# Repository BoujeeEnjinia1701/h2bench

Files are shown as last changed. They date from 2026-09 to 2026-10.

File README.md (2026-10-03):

# H2Bench

     

**Area:** Hydrogen · **TRL:** 3 of 9 (proof of concept on paper) · **Value-engineering target:** USD 885 (estimated cost USD 1056) · **Difficulty:** 4 of 5

A teaching bench that splits water with a small electrolyzer, stores a few liters of hydrogen at low pressure and runs a fuel cell, with meters so students can measure efficiency at each step. Protected by H2Guard.

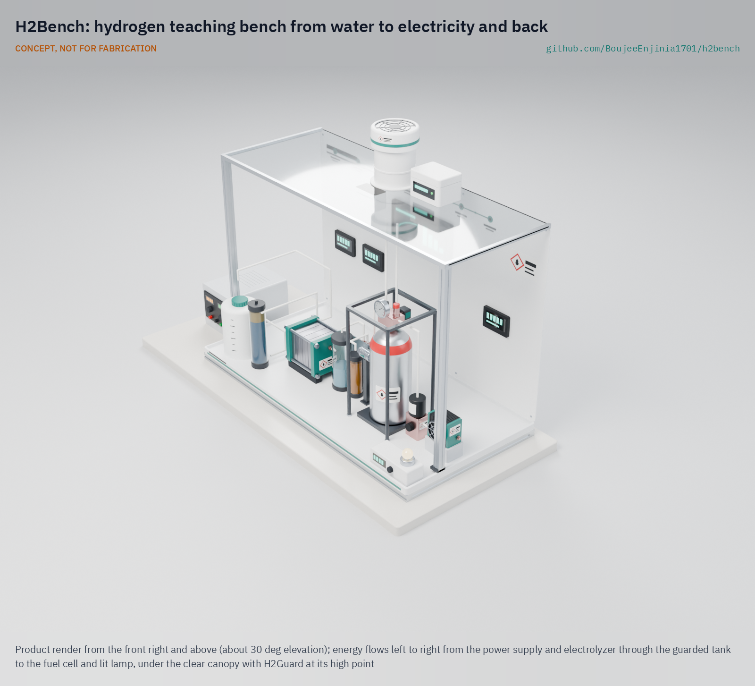
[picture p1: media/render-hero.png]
H2Bench: hydrogen teaching bench from water to electricity and back, product render


[Exploded render](media/render-exploded.png) · [Front render](media/render-front.png) · [Interactive 3D model](media/viewer.html) · [Concept blueprint (PDF)](media/concept-blueprint.pdf) · [General arrangement HBN-DWG-001 (PDF)](cad/drawings/HBN-DWG-001.pdf) · [Sizing calculations](docs/04-calcs/01-sizing.md) · [Prototype build plan](docs/05-build-plan.md) · [Design decisions](docs/06-design-decisions.md) · [Review note](docs/REVIEW.md)

## Concept rationale

Measuring electricity in, hydrogen made and electricity out gives students an honest sense of where hydrogen fits and where it does not. H2Bench works at tens of watts, large enough that meter and wiring errors do not swamp the result and small enough that the whole hydrogen inventory (about 7.9 L at up to 300 kPa gauge) could be released into a classroom without approaching a flammable mixture. A rigid buffer tank lets students count the hydrogen with the gas law, and the same pressure feeds the fuel cell without a compressor.

It is open and garage-buildable because the barrier for schools is cost and trust. A branded 12 W fuel cell stack alone lists at $482 to $576 ([Fuel Cell Shop](https://www.fuelcellshop.com/7-types-of-small-fuel-cell-by-price-point/t1363?currency=usd), [Fuel Cell Store](https://www.fuelcellstore.com/horizon-12-watt-pem-fuel-cell)), well over half the whole $850 bench budget, and a sealed kit cannot be inspected by a safety officer. Every part of H2Bench is off the shelf, the design files are under CERN-OHL-S-2.0, and its safety chain is the portfolio's own open H2Guard detector and interlock.

## Burning platform

Hydrogen is moving from strategy to construction faster than the people who can judge it are trained. Global hydrogen demand was almost 100 Mt in 2024, but low-emissions hydrogen was still less than 1 % of production, and installed water electrolysis capacity was only about 2 GW ([IEA, Global Hydrogen Review 2025](https://www.iea.org/reports/global-hydrogen-review-2025/executive-summary)). The European Union alone aims to produce 10 Mt of renewable hydrogen a year by 2030 ([European Commission](https://energy.ec.europa.eu/topics/eus-energy-system/hydrogen_en)).

The workforce to build this is short: more than half of some 700 energy companies, unions and training institutions surveyed by the IEA report critical hiring bottlenecks ([IEA, 2025](https://www.iea.org/news/energy-employment-has-surged-but-growing-skills-shortages-threaten-future-momentum)). And the key number every student should leave with is sobering: converting electricity to hydrogen and back with fuel cells returns only 27.4 to 48 % of the energy ([Oxford Institute for Energy Studies, 2025](https://www.oxfordenergy.org/wpcms/wp-content/uploads/2025/07/ET48-Power-to-Hydrogen-to-Power.pdf)). H2Bench lets them measure it.

## Where it could be used

### By industry

| Industry | Use |
| --- | --- |
| Secondary and vocational schools | A practical that follows one packet of energy from electricity to hydrogen and back, with students calculating each efficiency |
| Hydrogen technician training | Safe-handling drills on real hardware: purge, leak check, interlock test and shutdown |
| Universities | Electrochemistry and energy labs: polarization curves, Faraday efficiency, gas law and uncertainty analysis |
| Energy utilities and project developers | Induction training for staff moving from gas, power or oil into hydrogen projects |
| Science centers and outreach | Supervised demonstrations of hydrogen production and use, with a visible lamp load |
| Public sector and policy training | Showing decision makers the measured round-trip loss behind hydrogen storage proposals |

### By country or region

| Country or region | Why it matters there |
| --- | --- |
| European Union | Targets 10 Mt of domestic renewable hydrogen and 10 Mt of imports a year by 2030 ([European Commission](https://energy.ec.europa.eu/topics/eus-energy-system/hydrogen_en)), which needs technicians across member states. |
| United States | The DOE Hydrogen Program names teachers and students as target audiences and notes "a general lack of awareness of hydrogen as an energy alternative" ([US DOE](https://www.hydrogen.energy.gov/program-areas/education)). |
| India | The National Green Hydrogen Mission targets 5 Mt a year by 2030 and projects over 600,000 jobs; about 5,600 people had been certified in hydrogen skills ([PIB, Government of India](https://www.pib.gov.in/PressNoteDetails.aspx?id=155990&NoteId=155990&ModuleId=3)). |
| China | Holds 65 % of global installed electrolysis capacity ([IEA, 2025](https://www.iea.org/reports/global-hydrogen-review-2025/executive-summary)), the largest base of electrolyzers that trained operators will run. |
| Chile | Its national strategy aims to produce the world's most cost-competitive green hydrogen by 2030 and to rank among the three leading exporters by 2040 ([IEA policy database](https://www.iea.org/policies/12973-national-strategy-for-green-hydrogen)). |
| Namibia | The vice-chancellor of the Namibia University of Science and Technology has warned of a talent gap of up to 130,000 green hydrogen workers by 2040 ([The Namibian, 2025](https://www.namibian.com.na/namibia-risks-130-000-worker-shortage-in-green-hydrogen-sector/)); the university's IGNITE GH2 project is retraining 685 unemployed graduates and 40 instructors ([NUST, 2026](https://www.nust.na/igniting-namibias-green-hydrogen-dream-science-building-national-tvet-workforce-green-hydrogen)). |

## What sparked the idea

The idea traces back to William Grove's gaseous voltaic battery, first described in 1842 ([Grove, *Philosophical Magazine* 21, 1842](https://doi.org/10.1080/14786444208621600)). Grove recombined hydrogen and oxygen on platinum electrodes in dilute sulfuric acid to make a current, and he used that current to decompose water, running the cycle in both directions on one bench. His 1843 paper to the Royal Society set out to establish "the rationale of its action" by experiment and reports the battery decomposing water, among other compounds ([Grove, *Philosophical Transactions* 133, 1843](https://doi.org/10.1098/rstl.1843.0009)). H2Bench takes the same loop, electricity to hydrogen and back, and adds what a classroom needs that Grove's apparatus lacked: a meter at every stage, a counted quantity of gas and a hardwired safety chain.

## Problem

Students hear about the hydrogen economy but rarely measure it. Teaching kits are either toys or costly lab systems, and neither shows round-trip losses clearly. Branded 12 W fuel cell stacks alone list at about $480 to $580, and schools need detection and ventilation before they will host any hydrogen rig.

## Concept

A teaching bench that splits water with a small electrolyzer, stores a few liters of hydrogen at low pressure and runs a fuel cell, with meters so students can measure efficiency at each step. Protected by H2Guard.

In one lesson a 70 W PEM electrolyzer fills a 2 L tank from 70 to 300 kPa gauge in 17.7 min; a 12 W class fuel cell then runs a lamp at 10.8 W for 29.0 min. Students log every stage at 1 Hz and find a round trip of about 25 % (HHV basis), each stage measurable to within ±2 %. These are paper figures from the TRL 3 sizing note HBN-CAL-001, not measurements.

At TRL 3 the design meets eleven of its sixteen requirements on paper. Value-engineering target: USD 885. Estimated cost of the constructable design: USD 1056 (USD 171 over the target). The H2Guard interlock, electrolyzer back-pressure and hydrogen purity at the fuel cell are at risk. The model now carries the decisions of 2026-10-02: a catalytic deoxidizer between the separator and the drier, a 10 mm deck, and the bench supply beside the bench, which brings the bench to 24.4 kg (R13 met) ([design decisions register](docs/06-design-decisions.md)); see [docs/REVIEW.md](docs/REVIEW.md).

Full design precis: [docs/02-concept.md](docs/02-concept.md)

## Key components

- PEM electrolyzer stack, about 70 W (under 100 W)
- 2 L buffer tank at up to 300 kPa gauge, with a 310 kPa gauge supply cut, a 325 kPa gauge relief valve, pressure and temperature sensing (metal hydride and gasbag kept as options)
- PEM fuel cell, 12 W class (under 50 W), with regulator and solenoid valve
- Power meters on each stage, with a logger and display
- Water deionizer cartridge and reservoir
- H2Guard detector and interlock, sensing at the high point of a canopy hood
- Bench frame and canopy hood

The priced bill of materials is in [bom/bom.csv](bom/bom.csv). Value-engineering target: USD 885, with the bench supply in the kit. Estimated cost of the constructable design: USD 1056 (USD 171 over the target); USD 991 without the bench power supply; H2Guard excluded. See [docs/REVIEW.md](docs/REVIEW.md).

## Building the prototype

The design is constructable: every part can be cut, folded, drilled or bought, and fastens to the parts next to it ([HBN-DDR-003](docs/decisions/0003-design-for-construction.md)). The bench is a slotted aluminium extrusion frame under a 12 mm HDPE deck, with four posts and a top frame carrying the polycarbonate canopy and the printed instrument panel; every component stands on a small folded or cut mount screwed to the deck. The [prototype build plan](docs/05-build-plan.md) shows each component's making sketch, every joint and all 14 assembly steps in pictures, with the leak, cut-switch and interlock checks that come before any hydrogen is made. Decisions still open are in the [design decisions register](docs/06-design-decisions.md).

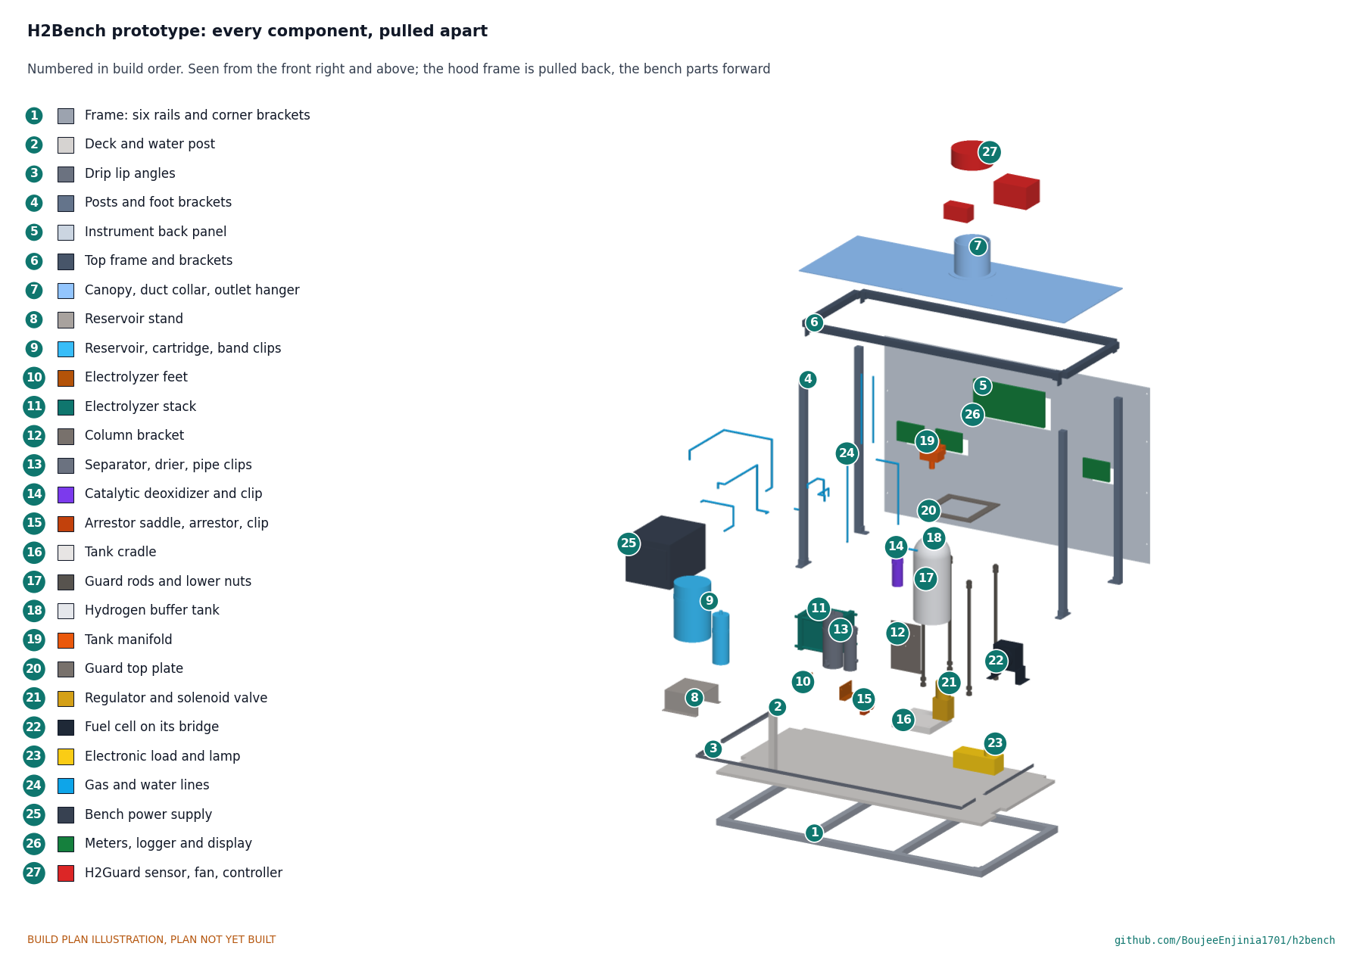
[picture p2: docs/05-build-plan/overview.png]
H2Bench prototype: every component, pulled apart and numbered in build order


## Safety

> Hydrogen is flammable from about 4 to 74 % in air and ignites very easily. Keep storage small and at low pressure (about 7.9 L at up to 300 kPa gauge), use only pressure parts rated 1 MPa or more, keep air out of the tank, and operate only with H2Guard active and under supervision. The power supply is mains powered; use an RCD or GFCI. Research and teaching use only; not certified laboratory equipment.

## Repository layout

| Folder | Contents |
| --- | --- |
| `docs/` | Problem, concept, requirements, calculations and design decisions |
| `cad/src/` | build123d Python source, the source of truth for all geometry |
| `cad/step/`, `cad/stl/` | Exported models for FreeCAD, other CAD tools and printing |
| `cad/drawings/` | 2D sketches and dimensioned drawings |
| `bom/` | Bill of materials |
| `electronics/` | KiCad schematics and PCB layouts |
| `firmware/` | Microcontroller code |
| `media/` | Renders, perspectives and photos |
| `build-log/` | Dated prototyping notes |

## Documentation

Controlled documents follow the portfolio [documentation standard](.kit/STANDARDS.md). Each carries a document ID (HBN-PRC-001 for the precis), a version and a revision history. Branded PDFs are built with `python .kit/render.py` and attached to GitHub Releases when a document is tagged, for example `HBN-PRC-001/v1.0`.

## Credits

Designed by Amish Chadha. See [CONTRIBUTORS.md](CONTRIBUTORS.md) for roles. To cite this design, use [CITATION.cff](CITATION.cff) (GitHub shows it as "Cite this repository").

AI assistance (Claude) was used to accelerate concept renders, prototype documentation and first-pass sizing calculations. Design direction and all decisions are Amish Chadha's, recorded in this repository's decision records (`docs/decisions/`).

## Licenses

- **Hardware** (CAD, drawings, BOM, electronics): [CERN-OHL-S v2](LICENSE)
- **Software** (firmware, scripts, notebooks): [MIT](LICENSE-SOFTWARE)

A project of the [Design Molecule](https://designmolecule.com) lab.

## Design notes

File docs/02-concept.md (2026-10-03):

---
doc_id: HBN-PRC-001
title: H2Bench design precis
project: H2Bench
doc_type: Design precis
version: "0.8"
status: Draft
date: '2026-10-02'
author: Amish Chadha
license: CERN-OHL-S-2.0
revisions:
- version: "0.1"
  date: '2026-09-25'
  author: Amish Chadha
  change: Initial scaffold
- version: "0.2"
  date: '2026-09-25'
  author: Amish Chadha
  change: Populate to TRL 2 (architecture, first-order numbers, design choices, safety, media)
- version: "0.3"
  date: '2026-09-25'
  author: Amish Chadha
  change: TRL 3 update; choices adopted for TRL 3 (HBN-DDR-001), numbers checked in HBN-CAL-001, parametric model and HBN-DWG-001, vent needle valve, media refreshed
- version: "0.4"
  date: '2026-09-25'
  author: Amish Chadha
  change: Recommendations accepted by Amish (DDR-002)
- version: "0.5"
  date: '2026-09-26'
  author: Amish Chadha
  change: Budget approved by Amish ($885)
- version: "0.6"
  date: '2026-10-01'
  author: Amish Chadha
  change: Constructable design (HBN-DDR-003) with posts and top frame, mounts, water lines; mass, cost against the value-engineering target, GA Rev P3; build plan and decisions register linked
- version: "0.7"
  date: '2026-10-02'
  author: Amish Chadha
  change: "Decisions of 2026-10-02: deoxidizer, tank material, worksheets and first use, H2Guard interface proposal; separator drain and demonstration-first safety rules"
- version: "0.8"
  date: '2026-10-02'
  author: Amish Chadha
  change: "Decisions carried into the design (2026-10-02): deoxidizer (line 19), 10 mm deck, supply beside the bench; figures from HBN-CAL-001 v0.6"
---

# H2Bench design precis

## Summary

H2Bench is a teaching bench that turns about 21 Wh of electricity into about 4.5 L of usable hydrogen in an 18 min fill, holds it in a 2 L tank at up to 300 kPa gauge (supply cut at 310 kPa gauge, relief at 325 kPa gauge), and returns about 5 Wh through a 12 W class fuel cell over about 29 min. Every stage is metered, so students measure a round-trip efficiency of about 25 % (estimate, HHV basis) from their own data and see where the other 75 % goes. The bench sits on an existing lab table under a canopy hood and runs only while the portfolio's H2Guard detector, extraction fan and interlock are active. All figures are checked in the calculation note HBN-CAL-001; they are paper estimates, not measurements.

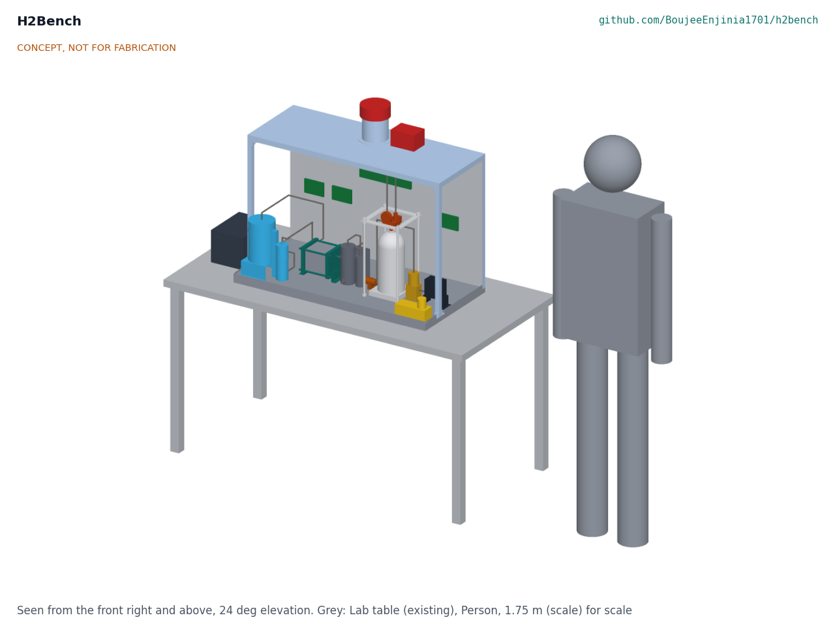
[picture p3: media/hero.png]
Hero render


*Figure 1. H2Bench on an existing lab table with a 1.75 m person for scale. Energy flows left to right: power supply, water, electrolyzer, gas treatment, buffer tank, regulator, fuel cell and lamp. Constructable model from `cad/src/model.py` (HBN-DDR-003).*

## How it works

A lesson runs in two halves.

1. **Fill (about 18 min).** The bench power supply (4) drives the PEM electrolyzer stack (6) in constant-current mode at about 9 A and 7.8 V. Deionized water from the reservoir (5) is split: oxygen vents into the hood, and hydrogen passes through the separator (7), the catalytic deoxidizer (19) and the drier (7), the check valve and flame arrestor (8), and into the buffer tank (9). The electrolyzer pushes the tank from 70 to 300 kPa gauge on its own; there is no compressor. If the fill is not stopped at 300 kPa gauge, a pressure switch on the manifold opens at 310 kPa gauge and a relay breaks the supply line, so the relief valve (325 kPa gauge) is only a backup. The cut is hardwired and does not depend on the logger firmware. Students log current, voltage, tank pressure and temperature, and compute the hydrogen made from the gas law and from Faraday's law. The difference is the Faraday efficiency.
2. **Discharge (about 29 min).** The solenoid valve and regulator (11) feed the fuel cell (12) at about 50 kPa gauge. The fuel cell runs the electronic load and lamp (13) at about 1.5 A. Students log power out and tank pressure fall, and plot the fuel cell's polarization curve by stepping the load.

The meters and logger (14) record every quantity at 1 Hz to a CSV file. The H2Guard sensor at the high point of the canopy hood (15) watches for hydrogen; on alarm it cuts the power supply output, closes the tank solenoid and runs the extraction fan at full speed.

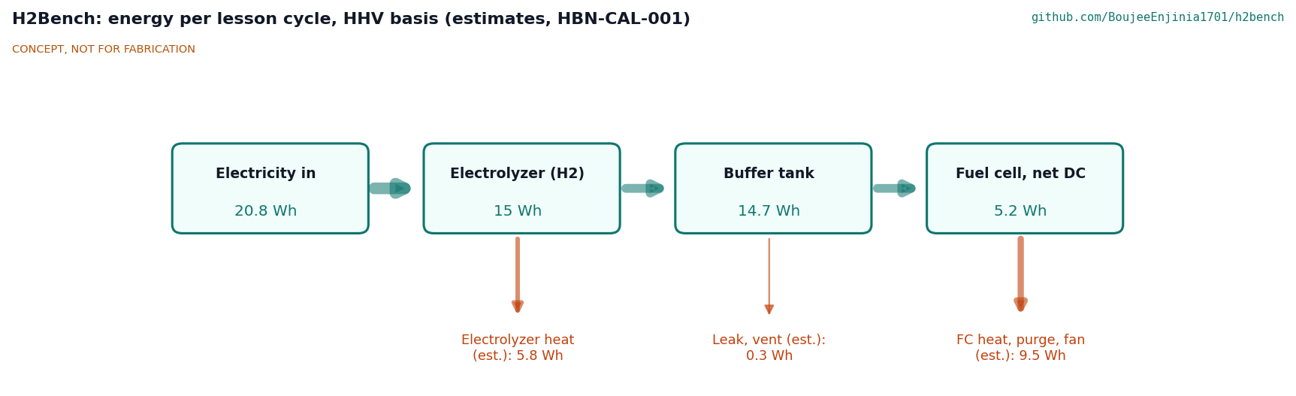
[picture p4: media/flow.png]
Energy flow


*Figure 2. Energy per lesson cycle, HHV basis, from HBN-CAL-001. All values are paper estimates: electrolyzer 72.2 % (voltage efficiency 75.9 %, Faraday efficiency 95 %), 2 % lost to leaks and venting in storage, fuel cell 35.5 % net (0.60 V per cell, 95 % fuel utilization, 0.9 W fan and controls).*

## Main components

Table 1. Main components. Numbers match `bom/bom.csv` and Figure 3.

| No. | Component | Function | Key figure (estimate) |
| --- | --- | --- | --- |
| 1 | Bench deck and extrusion frame | Carries everything, sits on the lab table | 900 x 450 mm |
| 2 | Instrument back panel | Printed energy-chain schematic; carries the meters | 570 mm tall |
| 3 | Canopy hood, duct and posts | Collects rising hydrogen at one point for sensing and extraction | 100 mm duct |
| 4 | Bench DC power supply | Constant-current drive for the electrolyzer | 0 to 30 V, 0 to 10 A |
| 5 | DI water reservoir and deionizer | Feed water at 1 µS/cm or less | About 3.4 g water used per fill |
| 6 | PEM electrolyzer stack | Splits water; pressurizes the tank | 4 cells, about 70 W, about 250 mL/min H2 |
| 7 | Gas and water separator, drier | Returns water; dries the hydrogen | Silica gel with indicator |
| 8 | Check valve and flame arrestor | Stops backflow and flame propagation into the stack | 7 kPa cracking pressure |
| 9 | Hydrogen buffer tank with guard | Stores the lesson's hydrogen | 2 L, 300 kPa gauge working, rated 1 MPa or more |
| 10 | Tank manifold | Pressure and temperature for the gas law; relief; gauge; vent needle valve; high-pressure cut switch | Cut at 310 kPa gauge; relief at 325 kPa gauge; vent in 3 min or more |
| 11 | Regulator and solenoid valve | Feeds the fuel cell; closes on alarm or power loss | About 50 kPa gauge out |
| 12 | PEM fuel cell | Converts hydrogen back to electricity | 12 W class, 13 cells, 154 mL/min H2 supplied |
| 13 | Electronic load and lamp | Steps the load for polarization curves; shows the output | 0 to 3 A |
| 14 | Meters, logger and display | Three power monitors, pressure and temperature, CSV at 1 Hz; relay that breaks the electrolyzer supply when the line 10 switch opens | ±1 % power; relay 10 A DC or more |
| 15 | H2Guard sensor, controller and fan | Detection, extraction and interlock (H2Guard project) | See H2Guard |
| 19 | Catalytic deoxidizer | Reacts oxygen carried across the stack membrane back into water before the drier | Palladium cartridge, 32 x 120 mm; assumed 99 % conversion |

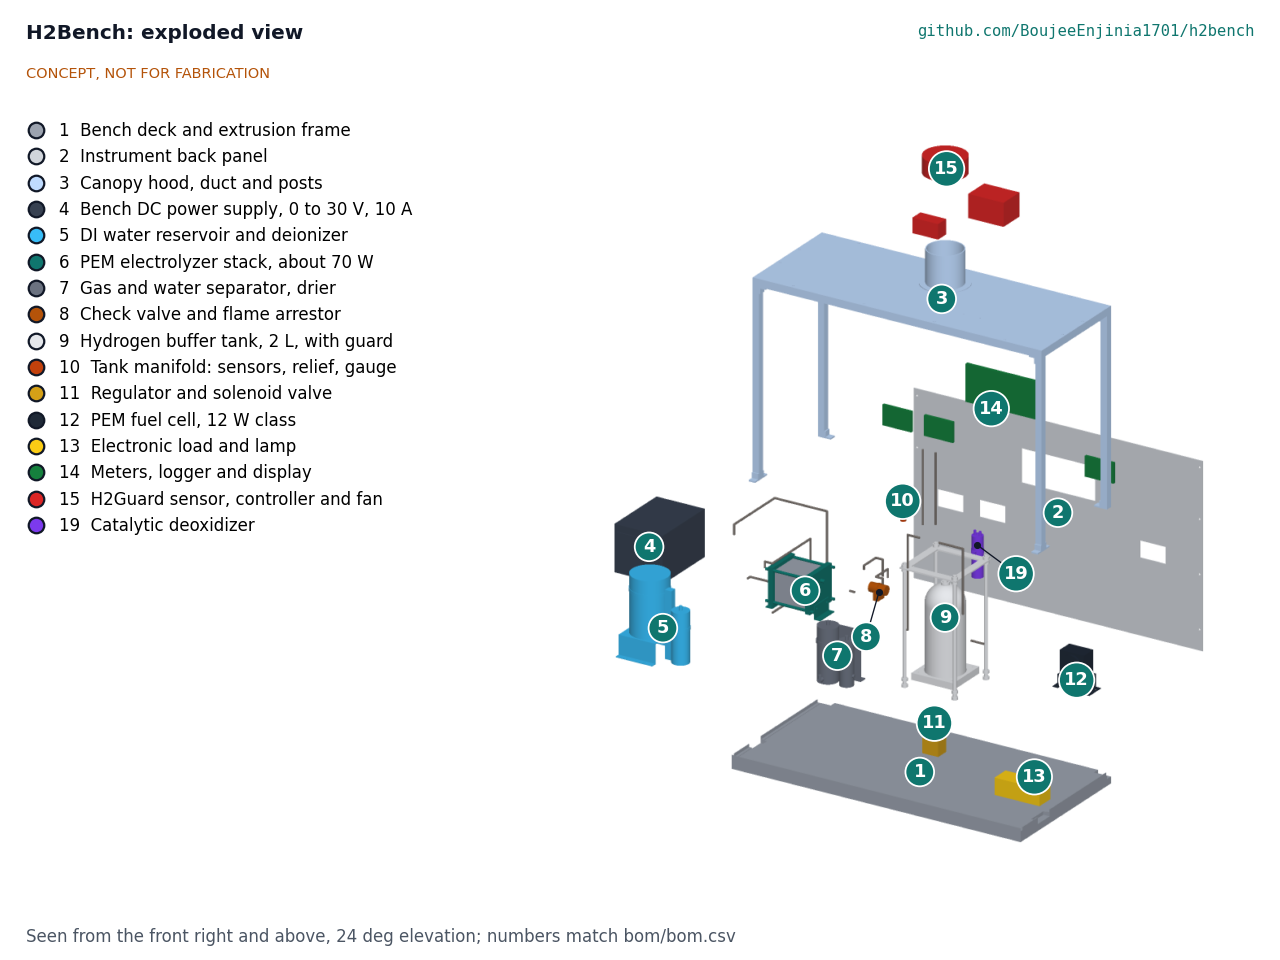
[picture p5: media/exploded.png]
Exploded view


*Figure 3. Exploded view with BOM numbers.*

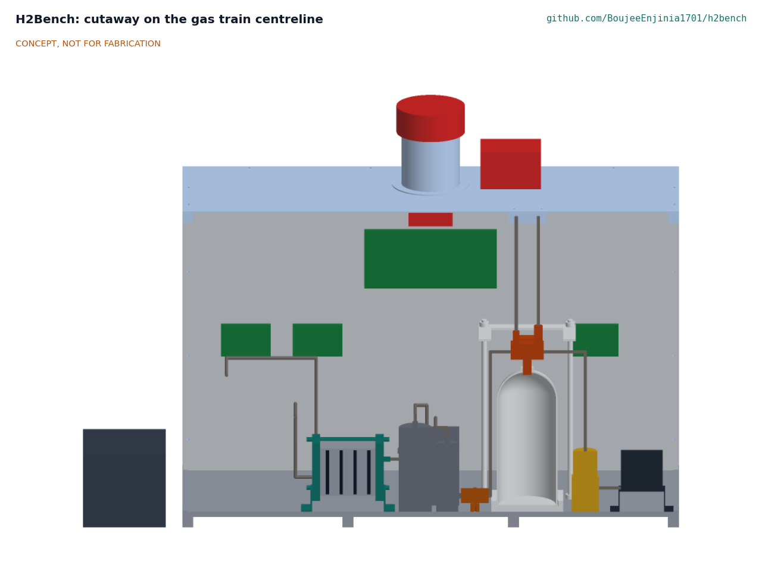
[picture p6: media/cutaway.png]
Cutaway


*Figure 4. Section on the gas train centreline, looking from the front. Left to right: power supply (4), electrolyzer (6) with its four membrane electrode assemblies between titanium plates, separator, deoxidizer and drier (7 and 19), check valve and flame arrestor (8), buffer tank (9) shown hollow inside its rod guard with the manifold (10) and the relief line rising to the canopy, regulator and solenoid (11) and fuel cell (12).*

The general arrangement, with the main dimensions and interfaces, is drawing HBN-DWG-001 Rev P4 ([`cad/drawings/HBN-DWG-001.pdf`](../cad/drawings/HBN-DWG-001.pdf)); STEP and STL exports are in `cad/step/` and `cad/stl/`.

## First-order numbers

The numbers below are checked in HBN-CAL-001 (`docs/04-calcs/01-sizing.md`), which also holds the assumptions and the results table against every requirement.

Table 2. Energy and gas per lesson cycle (HBN-CAL-001).

| Quantity | Value | Assumption |
| --- | --- | --- |
| Electrolyzer input | 70.2 W for 17.7 min, 20.8 Wh | 4 cells, 1.95 V per cell, 9 A |
| Hydrogen produced | 0.189 mol, 4.5 L at 20 °C, 15.0 Wh (HHV); 256 mL/min | Faraday efficiency 95 %; HHV 285.8 kJ/mol |
| Electrolyzer efficiency | 72.2 % (HHV) | Voltage efficiency 1.48 V / 1.95 V = 75.9 % |
| Compression penalty | 17.4 mV per cell, under 1 % | Electrochemical, 1 to 4 bar absolute on the H2 side |
| Tank content at 300 kPa gauge | 0.33 mol, 7.9 L at 20 °C, 0.66 g (8.5 L with the lines) | 2.000 L at 401 kPa absolute, 20 °C; 0.15 L outside the tank |
| Inventory at the relief setting | 9.0 L; 9.9 L at full relief lift on a 15 °C day | Relief 325 kPa gauge, 10 % overpressure at full lift |
| Usable swing | 300 down to 70 kPa gauge, 0.189 mol | Regulator needs about 20 kPa headroom above the fuel cell supply |
| Storage loss | About 2 %, 0.3 Wh | Leaks, purge of the lines; to be measured |
| Fuel cell output | 11.7 W gross, 10.8 W net, for 29.0 min, 5.2 Wh; 154 mL/min supplied | 13 cells at 0.60 V and 1.5 A; 95 % utilization; 0.9 W fan and controls |
| Fuel cell efficiency | 35.5 % net (HHV), 42.0 % (LHV) | Consistent with the 40 % system efficiency listed for the 12 W class ([Fuel Cell Store](https://www.fuelcellstore.com/horizon-12-watt-pem-fuel-cell)) |
| Round trip | 25.1 % (HHV) | Just below the 27.4 to 48 % range in [OIES (2025)](https://www.oxfordenergy.org/wpcms/wp-content/uploads/2025/07/ET48-Power-to-Hydrogen-to-Power.pdf), as expected at 12 W scale with a dead-end fuel cell |
| Heat released | About 20 W at the electrolyzer, about 19 W at the fuel cell | Losses in Figure 2 divided by run time |
| Oxygen vented | 2.3 L per fill | Half the hydrogen moles |
| Total release into a 30 m³ room | 0.030 % by volume, 0.75 % of the 4 % lower flammable limit | Relief-set inventory, well mixed |
| Venting 300 to 20 kPa gauge | 5.9 L over 3.0 min through the needle valve; peak 0.35 % by volume at the duct | 60 m³/h hood extraction |
| Stored pressure energy | 646 J (710 J at the relief setting) | Isentropic expansion of 2 L to 101 kPa absolute |
| Stored chemical energy | About 94 kJ (HHV), 80 kJ (LHV) | 0.33 mol |
| Hydrogen measurement | ±1.5 % per fill; each stage efficiency within ±1.8 % | 0.25 % FS transducer on 600 kPa, ±1 K, tank volume calibrated by water fill to ±1 % |
| Envelope and mass | 900 x 450 x 753 mm; 24.4 kg for the bench as moved, supply beside it (27.4 kg with the supply) | `cad/src/model.py`; mass estimate in HBN-CAL-001 |
| Parts cost | USD 1056, or USD 991 without the bench supply; USD 171 over the USD 885 value-engineering target | `bom/bom.csv`; H2Guard excluded |

The numbers show that one 90 min lesson holds a full cycle with 13 min to spare (R2), the round trip lands where published studies say it should, and students can measure each stage to better than ±2 %, so the bench teaches the right lesson. They also show three requirements at risk: the H2Guard interlock (R8), electrolyzer back-pressure (R10) and hydrogen purity at the fuel cell (R9, now with a deoxidizer fitted but no supplier data). Mass (R13) is met at 24.4 kg once the deck is 10 mm and the supply stands beside the bench. The 325 kPa gauge relief brings the inventory (R5) to met.

## Key design choices

Choices 1 to 10 are **decided by Amish, 2026-09-25: go with recommendation** (HBN-DDR-002). The open items are listed at the end of this section.

1. **Storage: rigid 2 L buffer tank at up to 300 kPa gauge.** Decided (HBN-DDR-002 D1). Options were: (a) rigid tank, pressurized by the electrolyzer; (b) metal hydride canister (stores more at lower pressure, but slow, costly and hides the gas law); (c) near-atmospheric gasbag or water-displacement gas holder with a small pump to feed the fuel cell. (a) was chosen because the fuel cell needs about 45 to 55 kPa gauge supply ([Fuel Cell Store](https://www.fuelcellstore.com/horizon-12-watt-pem-fuel-cell)) and pressure and temperature give students a direct measurement of the hydrogen. Condition: the electrolyzer must hold the back-pressure, 332 kPa over its oxygen side at the relief setting (R10, HBN-CAL-001); if not, fall back to (c).
2. **PEM electrolysis with deionized water, not alkaline.** Decided (HBN-DDR-002 D2). Alkaline cells are cheaper but need potassium hydroxide, a caustic electrolyte.
3. **Generic 12 W class fuel cell rather than a branded stack.** Decided (HBN-DDR-002 D3). A branded 12 W stack lists at $482 to $576; a generic stack is estimated at about $250, with a published polarization curve and a purity tolerance as purchase conditions; branded as the fallback.
4. **Measure hydrogen by pressure, volume and temperature, not by a mass flow meter.** Decided (HBN-DDR-002 D4). It is cheaper, and the gas law is itself a lesson. A mass flow meter could be an upgrade for university labs.
5. **Bench power supply in constant-current mode as the source.** Decided (HBN-DDR-002 D5). A small solar panel could be added later to show renewable-to-hydrogen; not in the first version.
6. **H2Guard as a hard dependency, costed in its own project and shipped with the bench.** Decided (HBN-DDR-002 D6). The bench cannot run without it.
7. **Tank kept above about 20 kPa gauge between lessons** so air cannot enter; a new or opened tank is purged with hydrogen by pressure cycling before first use (three fill and vent cycles to 300 kPa gauge reduce the air fraction to about 1.6 %). Decided (HBN-DDR-002 D7).
8. **Canopy hood with a single high point** so the sensor sees any leak first and the fan extracts it. Decided (HBN-DDR-002 D8).
9. **Value-engineering target of USD 885 with the bench power supply in the kit**, H2Guard costed in its own project. Decided (HBN-DDR-002 D9 and D10); `budget_usd` rose from $450 to $850, and to $885 on 2026-09-26; on 2026-10-01 Amish set it as a hypothetical control target, not a limit. Estimated cost of the constructable design: USD 999 (USD 114 over the target).
10. **Pressure protection and venting.** Relief valve at 325 kPa gauge (was 350) so the inventory stays under 10 L even at full lift; a pressure switch that cuts the supply at 310 kPa gauge so the relief valve is a backup only; vent needle valve set for 3 min or more; plug-in 30 mA RCD (BOM line 18). Decided (HBN-DDR-002 D11 to D14).

Open decisions, with options and recommendations, are kept in the design decisions register ([docs/06-design-decisions.md](06-design-decisions.md)). The constructable design, with the parts added so the bench can be built (four posts and a top frame, mounts for every component, water lines), is in HBN-DDR-003, and the build plan is [docs/05-build-plan.md](05-build-plan.md).

## Safety

> **Safety:** Hydrogen is flammable in air from about 4 to 74 % by volume and ignites with about 0.02 mJ, far less than most fuels; its flame is hard to see in daylight ([US DOE](https://www1.eere.energy.gov/hydrogenandfuelcells/pdfs/h2_safety_fsheet.pdf)). H2Bench is a research and teaching prototype, not certified laboratory equipment. Run it only under supervision, only with the H2Guard detector, fan and interlock active and tested, and never near open flames, heaters or sparking tools.

> **Safety:** The tank and lines are under pressure (up to 300 kPa gauge, supply cut at 310 kPa gauge, relief at 325 kPa gauge). Check that the pressure switch cuts the supply before each lesson series. Use only vessels and fittings rated 1 MPa or more and rated for hydrogen; never use plastic bottles. Keep the tank inside its guard, pipe the relief valve and manual vent into the hood, and never open a fitting while the system is pressurized.

> **Safety:** Vent slowly through the needle valve (3 min or more from 300 to 20 kPa gauge). A faster vent can raise the concentration at the duct past H2Guard's warning level (HBN-CAL-001 section 7).

> **Safety:** Keep air out of the tank. A hydrogen and air mixture inside a closed vessel can burn or detonate. Purge a new or opened tank with hydrogen by pressure cycling, and never vent it below about 20 kPa gauge.

> **Safety:** Drain the separator by hand only at the 20 kPa gauge holding pressure, under the hood, with H2Guard running (decided 2026-10-02).

> **Safety:** Run the bench first as an instructor-run class demonstration. Move to student group practicals only after a recorded run of attended fills, with H2Guard tested before each (decided 2026-10-02).

> **Safety:** The oxygen outlet of the electrolyzer must vent to the hood, away from the hydrogen outlet, so oxygen and hydrogen can never mix in a line.

> **Safety:** The bench power supply is mains powered. Use a supply with a protective earth, keep the mains lead off the wet deck, and fit a residual-current device (RCD or GFCI) on the bench socket. Water and electricity share the deck; keep the reservoir below and away from the supply.

> **Safety:** The electrolyzer and fuel cell stacks run warm (about 20 W of heat each) and the fuel cell's maximum stack temperature is about 55 °C. Allow cooling before handling.

## Open questions

- [ ] Can a generic electrolyzer stack at this size hold 332 kPa on the hydrogen side over the oxygen side, the relief setting plus the check valve (R10, HBN-CAL-001)?
- [ ] What hydrogen purity reaches the fuel cell after the separator and drier, and does the chosen fuel cell tolerate it (R9)? Decided 2026-10-02: a catalytic deoxidizer is fitted between separator and drier, and removed only if the stack supplier's data show oxygen within the 99.995 % limit at the lowest operating current.
- [ ] H2Guard alarm set point and response time; how the interlock reaches the power supply output and the solenoid (R8).
- [x] Tank: decided 2026-10-02, a certified aluminium cylinder (6061-T6 class) of about 2 L with a stamped working pressure of 1 MPa or more and a threaded neck; stainless only if a rated cylinder of about 1.0 kg or less is found.
- [ ] Is a 300 kPa gauge tank acceptable to school safety officers, or is option (c) (near-atmospheric storage with a pump) needed?
- [x] Curriculum and age group: decided 2026-10-02, post-16 vocational learners on hydrogen or renewable energy technician courses, aligned to the electrochemistry, gas safety and efficiency units of the first partner college's course. The first use is an instructor-run class demonstration; group practicals follow a recorded run of attended fills with H2Guard tested before each.
- [x] Budget for the kit: set to $885 by Amish on 2026-09-26, and on 2026-10-01 made a value-engineering target (R14).
- [ ] Which H2Guard output breaks the 9 A supply line, and at what voltage the tank solenoid runs (R8)? Decided 2026-10-02 to propose to H2Guard: a 24 V normally closed tank solenoid powered directly from H2Guard, and H2Guard's alarm contact in series with the 310 kPa cut relay; awaiting H2Guard.

Concept media: [blueprint sheet](../media/concept-blueprint.pdf), [interactive 3D model](../media/viewer.html).

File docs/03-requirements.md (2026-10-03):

---
doc_id: HBN-REQ-001
title: H2Bench requirements
project: H2Bench
doc_type: Requirements
version: "0.8"
status: Draft
date: '2026-10-02'
author: Amish Chadha
license: CERN-OHL-S-2.0
revisions:
- version: "0.1"
  date: '2026-09-25'
  author: Amish Chadha
  change: Initial scaffold
- version: "0.2"
  date: '2026-09-25'
  author: Amish Chadha
  change: First measurable requirements for TRL 2, with first-order status
- version: "0.3"
  date: '2026-09-25'
  author: Amish Chadha
  change: TRL 3 status from HBN-CAL-001; R14 scope states that H2Guard is costed in its own project (HBN-DDR-001)
- version: "0.4"
  date: '2026-09-25'
  author: Amish Chadha
  change: Recommendations accepted by Amish (DDR-002)
- version: "0.5"
  date: '2026-09-26'
  author: Amish Chadha
  change: Budget approved by Amish
- version: "0.6"
  date: '2026-10-01'
  author: Amish Chadha
  change: Constructable design (HBN-DDR-003); R13 mass and R15 guard clearance updated; R14 reported against the value-engineering target
- version: "0.7"
  date: '2026-10-02'
  author: Amish Chadha
  change: "Decisions of 2026-10-02: R13 counts the bench without its supply (10 mm deck decided); R9 deoxidizer decided; R8 interface proposal to H2Guard"
- version: "0.8"
  date: '2026-10-02'
  author: Amish Chadha
  change: "Decisions carried into the model (2026-10-02): R13 met at 24.4 kg; R9 at risk with the deoxidizer fitted; R14 USD 171 over the target"
---

# H2Bench requirements

These requirements were checked by calculation at TRL 3 in HBN-CAL-001 v0.3 (`docs/04-calcs/01-sizing.md`). Version 0.4 applies the decisions Amish accepted on 2026-09-25 (HBN-DDR-002): R14's limit is now the $850 `budget_usd` (was $450), with the bench power supply in the kit and H2Guard costed in its own project; R6 records the 325 kPa gauge relief and the 310 kPa gauge supply cut; and R10's target is restated from 300 kPa to 332 kPa, the relief setting plus the check valve, because a 300 kPa rating did not cover a relief event. Version 0.5 raises R14's limit to $885, the budget Amish approved on 2026-09-26 to cover the priced BOM (HBN-DDR-002). Version 0.6 follows the constructable design of HBN-DDR-003 and reports R14 against `budget_usd` as a value-engineering target, not a limit (Amish, 2026-10-01). Eleven requirements are met on paper, R14 is USD 171 over its value-engineering target, three are at risk (R8, R9 and R10) and one (R16) cannot be verified until hardware exists. Version 0.8 carries the decisions of 2026-10-02 into the model: R13 becomes met (24.4 kg for the bench as moved) and R9 moves from not met to at risk (deoxidizer fitted, no supplier data). "Met" means met by calculation or design review, not by test.

Table 1. Requirements and status at TRL 3.

| ID | Requirement | Target | Status (HBN-CAL-001) | Verification (TRL 3 or later) |
| --- | --- | --- | --- | --- |
| R1 | Measure the efficiency of each stage | Electrolyzer, storage, fuel cell and round trip, each to within ±5 % relative | Met: hydrogen per fill ±1.5 %, worst stage ±1.8 % | Uncertainty calculation (HBN-CAL-001 section 6) |
| R2 | Complete a full cycle in one lesson | Fill and discharge within 60 min of run time | Met: 17.7 min fill plus 29.0 min discharge, 46.7 min | Energy and flow calculation |
| R3 | Electrolyzer power | 100 W or less electrical input | Met: 70.2 W (79 W with aged cells) | Calculation; stack datasheet later |
| R4 | Fuel cell power | 50 W or less; 10 W or more net to run a visible load | Met: 10.8 W net, a 0.8 W margin (9.8 W if cells fall to 0.55 V) | Calculation; stack datasheet later |
| R5 | Limit the hydrogen inventory | 10 L or less at 20 °C and 101.3 kPa | Met: 8.5 L at 300 kPa gauge, 9.0 L at the 325 kPa gauge relief setting, 9.9 L at full relief lift on a 15 °C day | Gas law calculation |
| R6 | Limit storage pressure | Working pressure 300 kPa gauge or less; electrolyzer supply cut at 310 kPa gauge; relief at 350 kPa gauge or less; vessel rated 1 MPa or more | Met by design: cut 310 kPa gauge, relief 325 kPa gauge; hoop stress 18 MPa at 1 MPa | Component ratings |
| R7 | No flammable mixture in the room from a total release | Full inventory mixed into a 30 m³ room below 25 % of the lower flammable limit | Met: 0.030 % by volume, 0.75 % of LFL | Calculation |
| R8 | Interlock shuts down on a leak | H2Guard alarm cuts electrolyzer power and closes the tank solenoid within 2 s; fan runs | **At risk:** 1.1 s from H2Guard's TRL 2 figures, but H2Guard is at TRL 2 and its valve is 24 V against H2Bench's 12 V solenoid. Decided 2026-10-02 to propose to H2Guard a 24 V normally closed tank solenoid powered from H2Guard and its alarm contact in series with the 310 kPa cut relay | H2Guard design review |
| R9 | Hydrogen quality at the fuel cell | Purity as the stack requires (the 12 W class specifies 99.995 % or better) | **At risk:** water is removed by the drier and a catalytic deoxidizer (BOM line 19) now sits between separator and drier. At an assumed 99 % conversion the residual oxygen is 10 to 200 ppm for 0.1 to 2 % crossover, against 50 ppm for all impurities, and there is no supplier data. The deoxidizer is removable only if the stack supplier's data show oxygen within the 99.995 % limit at the lowest operating current | Supplier data, later gas test |
| R10 | Electrolyzer tolerates tank back-pressure | H2 side rated to 332 kPa or more over the O2 side (relief setting plus check valve; was 300 kPa) | **At risk:** the stack must hold 307 kPa while filling, 317 kPa at the supply cut and 332 kPa at the relief setting; no rating in hand | Supplier data |
| R11 | Water quality | Conductivity 1 µS/cm or less at the stack inlet, shown to students | Met by design (mixed-bed resin and conductivity check) | Datasheet |
| R12 | Log data students can analyze | Voltage, current, power, tank pressure and temperature at 1 Hz, saved as CSV | Met by design: 2,804 rows, about 224 kB per cycle | Firmware sketch review |
| R13 | Fit an existing lab bench | Footprint 1,000 x 500 mm or less; height 800 mm or less; mass 25 kg or less for the bench as moved (the bench supply ships in the kit but sits beside the bench, HBN-DDR-003 A1, 2026-10-02) | **Met:** 900 x 450 x 753 mm, 24.4 kg for the bench as moved with an aluminium tank (the supply stands beside it; 27.4 kg with the supply); the 10 mm deck of 2026-10-02 is in the model | Parametric model and mass estimate |
| R14 | Low cost and buildable | Parts cost reported against the USD 885 value-engineering target (`budget_usd`, was $450, then $850), including the bench power supply and excluding H2Guard, which is costed in its own project and shipped with the bench; hand tools only; no welding | USD 1056, USD 171 over the value-engineering target (USD 991 without the bench supply); hand tools only, no welding (HBN-DDR-003) | Priced BOM |
| R15 | Guard people from pressure parts | Tank inside a guard; relief and vent piped to the hood; no pressurized fitting that can be opened without a tool | Met by design: 50 mm guard clearance; relief and vent lines to the outlet hanger under the canopy | Design review |
| R16 | Set up and shut down quickly | Setup 15 min or less; tank vented and bench safe in 5 min or less | Not verifiable at TRL 3: the vent takes 3.0 min at the needle valve setting; setup needs a walk-through with hardware | Walk-through when hardware exists |

## Assumptions

- Electrolyzer: 4 cells at about 1.95 V and 9 A, Faraday efficiency 95 %; hydrogen higher heating value (HHV) 285.8 kJ/mol.
- Tank: 2.000 L internal plus 0.15 L of lines at tank pressure, filled from 70 to 300 kPa gauge (171 to 401 kPa absolute) at 20 °C; below 70 kPa gauge the regulator cannot hold the fuel cell supply. The full assumption list is in HBN-CAL-001 Table 1.
- Fuel cell: 13 cells at 0.60 V and 1.5 A, fuel utilization 95 % (the rest purged), about 0.9 W for fan and controls.
- Room: 30 m³, well mixed. The canopy hood exists because mixing near the leak is not instant; see HBN-PRC-001.
- Round-trip figures use the HHV basis. On a lower heating value (LHV) basis the hydrogen energy is about 15 % lower and the fuel cell efficiency correspondingly higher.

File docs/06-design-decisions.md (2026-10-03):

---
doc_id: HBN-DEC-001
title: H2Bench design decisions register
project: H2Bench
doc_type: Design decisions register
version: "0.3"
status: Draft
date: '2026-10-02'
author: Amish Chadha
license: CERN-OHL-S-2.0
revisions:
- version: "0.1"
  date: '2026-10-01'
  author: Amish Chadha
  change: Register opened with the open decisions from REVIEW.md, HBN-DDR-001 to 003 and the build plan work
- version: "0.2"
  date: '2026-10-02'
  author: Amish Chadha
  change: "Amish approved the recommendations for open decisions 1 to 8 (2026-10-02); moved to decisions made (HBN-DDR-003 accepted)"
- version: "0.3"
  date: '2026-10-02'
  author: Amish Chadha
  change: "Cost and mass restated after the 2026-10-02 decisions were carried into the model (USD 1056, 24.4 kg)"
---

# H2Bench design decisions register

Every design decision still to be made, and every decision made, in one place. Each decision is argued in full in its decision record under `docs/decisions/`; this register is the index Amish works from. The build plan (`docs/05-build-plan.md`) describes the design as it stands and does not list open decisions.

## Open decisions

None. All open decisions were decided on 2026-10-02.

## To confirm when parts are bought

*Table 2. Things to check on the real parts.*

| # | What to confirm | Why it matters | Source |
| --- | --- | --- | --- |
| 1 | The electrolyzer's hydrogen side is rated to 332 kPa or more over its oxygen side | R10; if not, the decided fallback (a gasbag with a pump) applies | HBN-DDR-002 D1, HBN-CAL-001 section 2 |
| 2 | The electrolyzer's end plates have two tapped mounting holes on each end face, about 50 mm apart and about 10 mm above the base, or the maker's own feet | The feet bolt there; otherwise the feet change | HBN-DDR-003 P7 |
| 3 | The electrolyzer's water inlet and oxygen outlet are on one end plate, inlet low and outlet high | The water lines are routed for that | HBN-DDR-003 P6 |
| 4 | The separator and drier are rated 1 MPa or more | They sit at tank pressure | HBN-PRC-001 safety notes |
| 5 | The tank is 110 mm across or less, stands on a flat base, and its neck thread suits the manifold adapter | The cradle pocket is 112 mm; the manifold screws into the neck | HBN-DDR-003 P10 |
| 6 | The fuel cell's mounting holes, and its hydrogen inlet on the side facing the regulator | The bridge top is drilled to suit | HBN-DDR-003 P11 |
| 7 | The panel meters' and display's cut-out sizes | The panel cut-outs are 80 x 50 mm and 230 x 100 mm | Build plan section 3.5 |
| 8 | The reservoir has a low side outlet and a vented lid; the deionizer cartridge takes 6 mm push-in or compression fittings | The water lines connect there | HBN-DDR-003 P6 |
| 9 | The 100 mm flanged duct collar fits the H2Guard fan | The fan sits on the spigot | HBN-DDR-003 P4 |
| 10 | The extrusion, brackets and T-nuts are all one 20-series system (6 mm slot) | Mixed systems do not fit | HBN-DDR-003 P1 |

## Value engineering

Value-engineering target: USD 885 (a hypothetical control target, not a limit; `budget_usd` in `project.yaml`). Estimated cost of the constructable design: USD 1056 (USD 171 over the target; the deoxidizer adds USD 60 and the 10 mm deck saves USD 3). Without the bench power supply it is USD 991 (USD 106 over), and USD 971 where the bench socket is also already RCD protected (USD 86 over). H2Guard is costed in its own project.

Main cost drivers:

- The two stacks: electrolyzer USD 155 and fuel cell USD 253 with their mounts, 41 % of the total.
- The frame, deck, hood and panel (BOM lines 1 to 3): USD 140, of which the construction changes added USD 45.
- The pressure parts: tank and guard USD 70, manifold USD 60, regulator and solenoid USD 40.

Savings worth trying:

- Letting the school supply the bench power supply (USD 85) would reverse HBN-DDR-002, D10; on 2026-10-02 the supply was kept in the kit, beside the bench, so this is not a saving to take. The "without the bench power supply" figures above do not compare like with like, because the USD 885 target was set with the supply included.
- Ask stack makers for an education bundle of electrolyzer and fuel cell: the two stacks are the largest single cost.
- Build the top frame and posts from plain 20 x 20 mm aluminium square tube with screwed corner plates instead of slotted extrusion and brackets: perhaps USD 20 to 30, at some cost to adjustability.
- Buy fittings, tubing and fasteners as one kit from a single gas-equipment supplier rather than line by line.

## Decisions made

*Table 3. Decisions made, newest first.*

| Date | Decision | Decided by | Record |
| --- | --- | --- | --- |
| 2026-10-01 | `budget_usd` is a value-engineering target, not a limit; cost is reported as over or under it | Amish: "the budgets are a hypothethical control target to ensure we are thinking along a value engineering lens. its ok to ensure wording reflects that the hypothesis budget was x - the real cost being accrued is y" | STANDARDS section 18; this register |
| 2026-09-30 | Make the design buildable while drawing the build plan; keep open decisions out of the build plan, in this register | Amish: "If you are realising that the design cannot be built as per concept - fix the design assumptions to match and be physically feasible as you draw the illustrations." | HBN-DDR-003 (accepted on 2026-10-02, below) |
| 2026-09-26 | Budget of USD 885 to cover the priced BOM (now the value-engineering target) | Amish: "i approve all the budget items." | HBN-DDR-002, budget section |
| 2026-09-25 | Relief valve at 325 kPa gauge; pressure switch cuts the supply at 310 kPa gauge; vent needle valve 3 min or more; plug-in 30 mA RCD | Amish: "i accept all your recommendations, go with them across all repos." | HBN-DDR-002 D11 to D14 |
| 2026-09-25 | Budget raised to about USD 850 with the bench supply in the kit; H2Guard costed in its own project and shipped with the bench | Amish, same instruction | HBN-DDR-002 D6, D9, D10 |
| 2026-09-25 | Rigid 2 L tank at up to 300 kPa gauge (gasbag with a pump as the fallback if R10 fails); PEM with deionized water; generic 12 W class fuel cell; hydrogen measured by pressure, volume and temperature; bench supply in constant-current mode | Amish, same instruction | HBN-DDR-001 items 1 to 5, HBN-DDR-002 D1 to D5 |
| 2026-09-25 | Tank kept above about 20 kPa gauge, new tank purged by three pressure cycles; canopy hood with a single high point; vocational technician training as the first users | Amish, same instruction | HBN-DDR-001 items 7, 8, 11; HBN-DDR-002 D7, D8 |
| 2026-09-25 | Settle the interlock interface with the H2Guard project | Amish, same instruction | HBN-DDR-002 D15 (the choices to propose were decided on 2026-10-02, below) |
| 2026-10-02 | Design for construction accepted as made: the changes P1 to P13 (frame joints, four posts and a top frame, mounts, water lines, guard of threaded rods) and their knock-on changes | Amish: "i approve your recommendations for all 555 open decisions." | HBN-DDR-003, Table 1 |
| 2026-10-02 | Mass (R13): options (a) and (b) together. The bench supply still ships in the kit (HBN-DDR-002, D10) but sits beside the bench, and the deck becomes 10 mm, giving 24.4 kg in the model, which holds as long as the tank is aluminium | Amish: "i approve your recommendations for all 555 open decisions." | HBN-DDR-003, A1 |
| 2026-10-02 | Separator water: option (a) for the prototype. The teacher drains the separator by hand at the 20 kPa gauge holding pressure, under the hood, with H2Guard running | Amish: "i approve your recommendations for all 555 open decisions." | HBN-DDR-003, A2 |
| 2026-10-02 | Hydrogen purity (R9): fit a catalytic deoxidizer between separator and drier now; remove it only if the stack supplier's data show oxygen in the hydrogen within the fuel cell's 99.995 % limit at the bench's lowest operating current | Amish: "i approve your recommendations for all 555 open decisions." | HBN-CAL-001 section 8, HBN-REQ-001 R9 |
| 2026-10-02 | H2Guard interface (R8): propose to H2Guard a 24 V normally closed tank solenoid powered directly from H2Guard so its alarm removes valve power; H2Guard's alarm contact in series with the 310 kPa cut relay so either one breaks the 9 A supply line; 60 m³/h stated as the hood extraction rate, separate from H2Guard's 150 m³/h room exhaust; and vocational technician training as the shared first user | Amish: "i approve your recommendations for all 555 open decisions." | HBN-DDR-002 D15, REVIEW.md |
| 2026-10-02 | Tank: a certified aluminium cylinder (6061-T6 class) of about 2 L with a stamped working pressure of 1 MPa or more and a threaded neck; stainless only if a rated stainless cylinder of about 1.0 kg or less is found | Amish: "i approve your recommendations for all 555 open decisions." | HBN-DDR-002 O3 |
| 2026-10-02 | First worksheets: for post-16 vocational learners on hydrogen or renewable energy technician courses, aligned to the electrochemistry, gas safety and efficiency units of the first partner college's course | Amish: "i approve your recommendations for all 555 open decisions." | HBN-DDR-002 O1 |
| 2026-10-02 | First use: an instructor-run class demonstration; group practicals only after the bench has a recorded run of attended fills with H2Guard tested before each | Amish: "i approve your recommendations for all 555 open decisions." | HBN-DDR-002 O2 |

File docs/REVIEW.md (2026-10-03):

# Review note: H2Bench

## Session 2026-10-01: design for construction and prototype build plan (kit 1.7.0)

Kit 1.7.0 installed (`.kit/`, `.claude/commands/`; `CLAUDE.md` replaced from `.kit/CLAUDE.md`). Following `.claude/commands/build-plan.md` and STANDARDS section 18, the design was checked for how each part is made and joined, made constructable under Amish's 2026-09-30 instruction ("If you are realising that the design cannot be built as per concept - fix the design assumptions to match and be physically feasible as you draw the illustrations."), and the illustrated build plan and design decisions register were written. All changes are open for Amish's review in HBN-DDR-003.

### Design changes made for construction (HBN-DDR-003)

- Frame: six cut lengths of 20-series extrusion (2 x 900, 4 x 410) with eight inside corner brackets, in place of one fused shape.
- Drip lip: 10 x 10 x 1.5 mm aluminium angle screwed on silicone (was moulded into the HDPE deck, 8 mm); the panel closes the back.
- Hood: four posts on the frame through deck notches with foot brackets, and a top frame (2 x 860, 2 x 305) carrying the canopy; was two front posts standing on the lip and a cantilevered canopy.
- Instrument panel: screwed to the rear posts, standing on the deck on silicone; 550 mm tall (was 570, floating), with meter and display cut-outs.
- Duct collar: a bought flanged spigot through a 106 mm hole (was fused into the canopy).
- Relief and vent lines: both clipped to a new outlet hanger, ending 7 mm below the canopy; the vent line was missing and the relief line ended against the sheet.
- Water side added: reservoir on a 60 mm folded stand, 150 mm deionizer cartridge, three water lines, water ports on the left end plate; oxygen vents through the reservoir lid.
- Electrolyzer: tie rods moved clear of the cell plates (they cut 2 mm in); two 40 x 20 x 3 mm angle feet bolted to the end plates; base 20 mm above the deck (was 13).
- Separator and drier: on a folded column bracket with pipe clips; gas loops over from the separator top to the drier top; drain valve on the separator (water returned by hand, proposed, A2).
- Arrestor: lowered to 60 mm in an HDPE saddle, straight off the drier outlet; the line to the tank clears it by 9 mm.
- Tank guard: M10 threaded rods in deck tee nuts and a bolted 4 mm top plate (was loose rods and a welded ring); tank in a 20 mm pocketed HDPE cradle, 8 mm lower.
- Fuel cell: on a folded 2 mm bridge open front and back (was a solid block).
- Water post (20 x 20 extrusion) with band clips for the reservoir and cartridge; every mount fixed with 5 mm self-tapping screws.
- Calculation correction: guard clearance 50 mm, not 18 mm (the rods stand at the corners).

`cad/src/model.py` now builds every part separately and runs 135 constructability checks (`--check`): no unintended overlaps, 70 contacts, 16 clearances, every part supported; all pass.

### Results

- Mass 28.0 kg with the bench supply (was 25.3), 25.0 kg without; R13 at risk by 3.0 kg (proposed A1).
- Value-engineering target: USD 885. Estimated cost of the constructable design: USD 999 (USD 114 over the target); BOM lines 1, 3, 5, 6, 7, 8, 9, 12, 16 and 17 repriced.
- Requirements: 10 met, R14 reported against the value-engineering target, 1 not met (R9 purity), 3 at risk (R8, R10, R13), 1 not verifiable (R16). No energy, gas, pressure or venting figure changed.

### Files

- New: `docs/decisions/0003-design-for-construction.md` (HBN-DDR-003 v0.1, Draft), `docs/05-build-plan.md` (HBN-BLD-001 v0.1), `docs/06-design-decisions.md` (HBN-DEC-001 v0.1), `cad/src/build_plan_media.py`, `docs/05-build-plan/` (overview, 9 joints, 14 steps, piping and wiring diagrams), `cad/drawings/HBN-DWG-101` to `114` (14 making sketches).
- Updated: `cad/src/model.py`, `cad/src/sheets.py` (HBN-DWG-001 Rev P3), `cad/src/concept_media.py`, STEP and STL, all concept media (`media/hero.png`, `concept-blueprint`, `cutaway.png`, `exploded.png`, `flow.png`, `model.glb`, `viewer.html`), `docs/04-calcs/sizing.py` and `results.csv`, HBN-CAL-001 v0.4, HBN-REQ-001 v0.6, HBN-PRC-001 v0.6, HBN-PRB-001 v0.6, `bom/bom.csv`, `bom/bom-notes.md`, `project.yaml` (`design_state: constructable`, evidence), `README.md` (links, cost lines, "Building the prototype"), PDFs in `docs/pdf/`.

### Proposed, awaiting Amish

All open decisions are in the register (`docs/06-design-decisions.md`): accepting HBN-DDR-003; mass (A1: carry the supply separately and use a 10 mm deck, recommended); separator water returned by hand (A2); hydrogen purity (R9); the H2Guard interface; tank material; curriculum; demonstration or practical first.

### Stale images (made on Amish's Mac)

The design changed visibly (rear posts, top frame, tank 8 mm lower, new mounts and water lines), so `media/render-hero.png`, `media/render-exploded.png`, `media/render-front.png`, `media/card.png` and `media/social-preview.png` are stale, and `cad/src/product_model.py` still describes the concept. They were not regenerated here.

### Safety

Unchanged hazards (hydrogen, pressure, mains near water). The build plan keeps every hydrogen and pressure step behind safety stops: nitrogen leak test and cut-switch test before any hydrogen, H2Guard tested before the first fill, purge by three pressure cycles, attended first fill.

### Recommended next step

Amish to review HBN-DDR-003 and the register. TRL 4 remains on hold.

## Session 2026-09-25: recommendations accepted

On 2026-09-25 Amish wrote: "i accept all your recommendations, go with them across all repos." Every item with a recommendation is now "Decided by Amish, 2026-09-25: go with recommendation", recorded in `docs/decisions/0002-recommendations-accepted.md` (HBN-DDR-002 v0.1). HBN-DDR-001 moved to v0.2 with the same wording.

### Decisions applied and what changed

- **D1 to D8 (wording only):** rigid 2 L tank, PEM, generic 12 W fuel cell, gas-law measurement, bench supply as the source, H2Guard costed separately and shipped with the bench, tank kept above 20 kPa gauge with purging, vocational training first, canopy hood with a single high point.
- **D9 and D10, budget:** `budget_usd` $450 to $850 in `project.yaml`, with the bench power supply in the kit (BOM line 4). R14 restated as $850 including the supply. README cost lines updated.
- **D11, relief:** 350 to 325 kPa gauge. Inventory at full lift and 15 °C 10.5 to 9.9 L (R5 at risk to met); at the relief setting 9.6 to 9.0 L; stored pressure energy at the relief setting 776 to 710 J; room release 0.032 to 0.030 % by volume.
- **D12, supply cut:** a pressure switch on the manifold opens at 310 kPa gauge and a relay (rated 10 A DC or more) breaks the electrolyzer supply, hardwired, independent of the logger firmware. Membrane load at the relief setting 357 to 332 kPa (317 kPa at the cut); R10's target restated from 300 to 332 kPa. BOM line 10 $45 to $60, line 14 $30 to $35: total $865 to $885 ($800 to $820 without the supply). Mass 25.2 to 25.3 kg.
- **D13 and D14:** vent needle valve 3 min or more and the plug-in RCD (line 18) confirmed; already in the design.
- **D15, H2Guard interface:** listed below as a cross-repo action.
- Files: `cad/src/model.py` (cut switch on the manifold; STEP and STL re-exported, clash check 0), `cad/src/sheets.py` (HBN-DWG-001 Rev P1 to P2: relief, cut, mass notes), `cad/src/concept_media.py` (key figure), `docs/04-calcs/sizing.py` and HBN-CAL-001 v0.2 with `results.csv`, HBN-PRB-001 v0.4, HBN-PRC-001 v0.4, HBN-REQ-001 v0.4, `bom/bom.csv`, `bom/bom-notes.md`, `README.md`. All PDFs, drawings and media regenerated; hero, blueprint, exploded and drawing checked by eye; the footer now reads designmolecule.com.
- README: "What sparked the idea" rewritten around William Grove's 1842 gas voltaic battery, whose current he used to electrolyze water; the earlier text about a portfolio review was removed. No pitch or problem rewording was recommended, so none was applied.

### Requirement status (HBN-CAL-001 v0.2)

Met 10 (was 9), not met 2, at risk 3 (was 4), not verifiable at TRL 3 1.

| ID | Result | Status |
| --- | --- | --- |
| R9 | Oxygen crossover unknown, no deoxidizer; fuel cell listing asks for 99.995 % | **Not met** |
| R14 | $885 full, $820 without the supply, $800 minimum; against $850 | **Not met** |
| R8 | 1.1 s trip; H2Guard valve 24 V against the 12 V solenoid; supply-break output undefined | At risk |
| R10 | Stack must hold 332 kPa over the O2 side; no rating in hand | At risk |
| R13 | 25.3 kg against 25 kg (22.3 kg without the supply) | At risk |
| R16 | Vent 3.0 min; setup needs hardware | Not verifiable at TRL 3 |
| R1 to R7, R11, R12, R15 | R5 now 9.9 L worst case | Met |

### Still awaiting Amish (no recommendation was made)

- Curriculum and age group for the first worksheets.
- Class demonstration or group practical first.
- Aluminium or stainless tank.
- Mass (R13): accept 25.3 kg, carry the supply separately, or a 10 mm deck.
- Cost (R14): where to find the $35 over the $850 budget. **Decided by Amish, 2026-09-26: budget set to $885 to cover the priced BOM; see "Session 2026-09-26: budget approved".**

### Cross-repo actions

- **H2Guard** (not edited from this repo): settle (1) the valve voltage, 24 V in H2Guard against H2Bench's 12 V tank solenoid; (2) which H2Guard output breaks H2Bench's 9 A DC supply line (the new 310 kPa gauge cut relay could share that break point); (3) hood extraction, 60 m³/h through the H2Bench canopy against H2Guard's 150 m³/h room exhaust; (4) first user, university teaching lab in H2Guard against vocational training here.

### TRL

`trl: 3` and `trl_target: 3` are unchanged. TRL 4 remains on hold by Amish's instruction: no build, test, purchasing, supplier trials, PCB or firmware beyond a sketch was started.

## Session 2026-09-25: TRL 3

### What was done

- `docs/decisions/0001-trl2-review-decisions.md` (HBN-DDR-001 v0.1): the eight TRL 2 recommendations adopted for TRL 3 work under Amish's 2026-09-25 instruction, open for his review, and the items that stay open.
- `docs/04-calcs/01-sizing.md` (HBN-CAL-001 v0.1) with `docs/04-calcs/sizing.py` and `docs/04-calcs/results.csv`: electrolyzer and fill, inventory and pressure, fuel cell, energy balance, measurement uncertainty, hood and venting, interlock, water and drier, envelope and mass, cost and logging, with a results table for R1 to R16. The script reads the tank and bench dimensions from the model and the prices from the BOM.
- `cad/src/model.py`: parametric build123d model (frame, deck, back panel, canopy with duct, supply, reservoir, 4-cell electrolyzer with membranes and ports, separator and drier, arrestor, 2.000 L tank sized from its volume parameter with guard, manifold with relief and vent needle valve, regulator and solenoid, 75 x 47 x 70 mm fuel cell, load, meters, H2Guard stand-in, 6 mm gas lines). Exports `cad/step/` and `cad/stl/` (assembly, frame and hood, tank module, electrolyzer); clash check finds no overlaps.
- `cad/src/sheets.py` and `cad/drawings/HBN-DWG-001.svg`, `.pdf`, `.png`: general arrangement at Rev P1, marked "CONCEPT, NOT FOR FABRICATION" and "PRELIMINARY, NOT FOR FABRICATION". HBN-DWG-001 was free because the concept blueprint uses HBN-DWG-010.
- `bom/bom.csv` (18 lines, all priced with a supplier type) and `bom/bom-notes.md`. Line 18 (plug-in 30 mA RCD, $20) is new; lines 6, 10, 12 and 16 were updated.
- `cad/src/concept_media.py` now builds from `model.py`; all media regenerated (hero, blueprint, cutaway, exploded, flow, `model.glb`, `viewer.html`), checked by eye, and the temporary `media/_views*` folders deleted. The kit's cutaway cuts at the mean Y of all parts, which missed the gas train, so the script renders its own cutaway on the gas train centreline.
- `docs/01-problem.md`, `docs/02-concept.md` and `docs/03-requirements.md` moved to v0.3 with the adopted choices, HBN-CAL-001 numbers and a status column from the CAL.
- `project.yaml`: trl 3, trl_target 3, trl_evidence updated; `budget_usd`, pitch and problem unchanged. `README.md`: TRL badge, links, Concept numbers and cost line.

### Requirements (HBN-CAL-001)

Nine met, two not met, four at risk, one not verifiable at TRL 3.

| ID | Result | Status |
| --- | --- | --- |
| R9 | Oxygen crossover unknown, no deoxidizer; fuel cell listing asks for 99.995 % | **Not met** |
| R14 | $865 full, $800 without the bench supply, $780 minimum; against $450 (and $850 proposed) | **Not met** |
| R5 | 9.6 L at the relief setting, but 10.5 L at full relief lift on a 15 °C day | At risk |
| R8 | 1.1 s trip to valve closed from H2Guard's TRL 2 figures; 24 V and 12 V valve mismatch | At risk |
| R10 | Stack must hold 357 kPa over the O2 side at the relief setting; no rating in hand | At risk |
| R13 | 900 x 450 x 755 mm, but 25.2 kg against 25 kg (22.2 kg without the supply) | At risk |
| R16 | Vent 3.0 min; setup needs hardware | Not verifiable at TRL 3 |
| R1, R2, R3, R4, R7 | ±1.8 % worst stage; 46.7 min cycle; 70.2 W; 10.8 W net; 0.8 % LFL in 30 m³ | Met |
| R6, R11, R12, R15 | Pressure ratings, water quality, logging, guard | Met (design review) |

Corrections to TRL 2 numbers: the 7.9 L "at the relief setting" was the tank alone at 300 kPa gauge; with the lines it is 9.6 L at the relief setting and 10.5 L at full lift. Mass rises from about 18 to 25.2 kg. Cost rises from $845 to $865 with the RCD line. The fuel cell's 146 mL/min was the reacted flow; it draws 154 mL/min. Bench height is 755 mm, not about 770 mm. R10's 300 kPa target does not cover a relief lift (357 kPa needed). R4 has only a 0.8 W margin.

Key numbers: 70.2 W electrolyzer, 256 mL/min, 17.7 min fill of 0.189 mol (4.5 L); 10.8 W net fuel cell for 29.0 min, 5.2 Wh; round trip 25.1 % (HHV); 646 J stored pressure energy at 300 kPa gauge; hydrogen per fill measured to ±1.5 %; drier lasts about 110 fills.

### Decisions recorded (HBN-DDR-001)

Decided by Amish, 2026-09-25: go with recommendation (HBN-DDR-002; recorded in this session as adopted for TRL 3, open for his review): rigid 2 L tank at up to 300 kPa gauge (gasbag with pump as the fallback if R10 fails); PEM, not alkaline; generic 12 W class fuel cell with a polarization curve as a purchase condition; hydrogen measured by pressure, volume and temperature; bench supply in constant-current mode as the source; H2Guard costed in its own project and shipped with the bench (applied to the R14 scope); tank kept above 20 kPa gauge with pressure-cycle purging; vocational technician training as the first users. No pitch or problem rewording was recommended, so none was applied.

### Still awaiting Amish (as of this session; see the recommendations-accepted session above for the current status)

- **Budget:** Decided by Amish, 2026-09-25: go with recommendation, `budget_usd` $850 (HBN-DDR-002 D9). At the time: about $850 recommended at TRL 2; `budget_usd` stayed $450. The full kit is $865, $15 over even the recommended figure; without the bench supply it is $800.
- Whether the bench power supply is in the kit (BOM line 4). Now Decided by Amish, 2026-09-25: go with recommendation: in the kit (D10).
- Canopy hood with a single high point (not in the TRL 2 review list, so not adopted; kept as the working design). Now Decided by Amish, 2026-09-25: go with recommendation (D8).
- Curriculum alignment, class demonstration or group practical first, and aluminium or stainless tank (no recommendation made). Still proposed, awaiting Amish.
- Engineering proposals from this session: relief at 325 kPa gauge (329 kPa gauge or less keeps R5 at full lift); a 310 kPa gauge cut of the supply so the relief valve is a backup; vent needle valve set for 3 min or more; plug-in RCD line. Now Decided by Amish, 2026-09-25: go with recommendation (D11 to D14).
- Mass (R13): accept 25.2 kg, carry the supply separately, or use a 10 mm deck (saves 0.77 kg). No recommendation; still proposed, awaiting Amish.

### Cross-repo notes (H2Guard, not edited)

H2Guard is not one of the batch's shared components, but H2Bench depends on it, so its REVIEW.md and documents were read. Consistent: H2Guard's trip to valve closed within 2 s (HGD-REQ-001 R4) matches R8, and its inventory rule (300 L for 30 m³) is met thirtyfold. Conflicts to resolve with H2Guard: (1) its valve is a 24 V normally closed part, while H2Bench's tank solenoid is 12 V; (2) it is not stated which H2Guard output breaks H2Bench's 9 A DC supply line; (3) H2Guard models its fan as a 150 m³/h room exhaust, while H2Bench assumes 60 m³/h through its canopy duct; (4) H2Guard recommends a university teaching lab as first user, H2Bench vocational training.

### Safety concerns

- Hydrogen is flammable from 4 to 74 % with a 0.02 mJ ignition energy and a nearly invisible flame; the bench must never run without H2Guard detection, extraction and interlock.
- Venting a full tank faster than about 90 s can raise the duct concentration past H2Guard's warning; the needle valve is set for 3 min or more.
- At the relief setting the tank holds 776 J of pressure energy; only 1 MPa rated metal parts, guard in place.
- The relief lift loads the electrolyzer membrane to 357 to 392 kPa; an unrated stack could fail and mix hydrogen into the oxygen side. The 310 kPa gauge supply cut is proposed.
- Oxygen crossover also puts some oxygen into the stored hydrogen; far below a flammable mixture, but unquantified.
- Mains supply near water: RCD (line 18) and earthed supply. Warm stacks: about 20 W of heat each. Users under 18 only under supervision.
- Research and teaching prototype, not certified laboratory equipment.

### Other notes

- No TRL 4 material exists (`build-log/` holds only its README; `electronics/` and `firmware/` are empty). None was created.
- Citations checked with WebFetch on 2026-09-25: the Fuel Cell Store 12 W listing (7.8 V at 1.5 A, 13 cells, 0.45 to 0.55 bar, 99.995 %, 0.18 L/min, 40 %, 55 °C, 5 to 30 °C, 275 g, $576) and the Ecofin Namibia report (130,000 workers by 2040, attributed to the NUST vice-chancellor; still a news report of a statement, not a study). The MSE listing confirms a single-cell 300 mL/min stack at $1,396.95 but states no output pressure, so the TRL 2 claim "up to about 0.4 MPa" was removed from HBN-PRB-001. Generic stack prices (BOM lines 6 and 12) remain unverified estimates.
- The `model.py` assemblies copy each shape, because a build123d shape can have only one parent compound; without this the STEP export and drawing silently lost parts.

### Recommended next step

TRL 4 is on hold by Amish's instruction, so the next step is a review, not a build: Amish to decide the budget (and whether the supply is in the kit), confirm or reject the relief, supply-cut and RCD proposals, and settle the H2Guard interface points with that project. For the record only, TRL 4 would need a named electrolyzer with a back-pressure rating of at least 357 kPa and an oxygen-in-hydrogen figure, fuel cell supplier acceptance of the gas, an H2Guard design at TRL 3 with a defined interlock output, a lab test report (TST, environment: lab) and build log entries.

## Session 2026-09-25: /populate to a strong TRL 2

### What was done

- `docs/01-problem.md` (HBN-PRB-001 v0.2): problem with cited sources, users, operating environment, constraints, out of scope, prior work and open questions. No co-design checklist existed, so none was kept.
- `docs/03-requirements.md` (HBN-REQ-001 v0.2): 16 measurable requirements (R1 to R16) with targets, estimated status and assumptions.
- `docs/02-concept.md` (HBN-PRC-001 v0.2): lesson sequence, 15 numbered components, energy and gas balance, nine proposed design choices, safety section and open questions.
- `cad/src/concept_media.py`: massing model of the bench (15 BOM parts, plus the electrolyzer cell block shown as unnumbered parts) on an existing lab table, with a 1.75 m person placed on the floor as a context part.
- `media/`: `hero.png`, `concept-blueprint.png`, `.pdf` and `.svg`, `model.glb` and `viewer.html`, `exploded.png` with callouts 1 to 15, `cutaway.png` (electrolyzer membranes and hollow tank), and `flow.png` (energy per lesson, all values labeled estimates).
- `bom/bom.csv`: 17 rows, numbered to match the exploded view (rows 16 and 17 are not modeled), with indicative USD prices; `bom/bom-notes.md` updated.
- `README.md`: hero image and links line; Concept rationale, Burning platform, both "Where it could be used" tables and "What sparked the idea" expanded with cited figures; Problem, Concept, Key components and Safety brought in line with the concept.
- `docs/pdf/`: branded PDFs of the three controlled documents.
- `project.yaml` is unchanged. The pitch ("a few liters of hydrogen at low pressure") and problem remain accurate.

### Key results (estimates, to be checked at TRL 3)

| Quantity | Estimate | Requirement |
| --- | --- | --- |
| Electrolyzer input | About 70 W (4 cells, 9 A) | R3 met |
| Fill time, 70 to 300 kPa gauge | About 18 min, 20.8 Wh in | R2 met |
| Hydrogen made per fill | 0.189 mol, about 4.5 L, 15.0 Wh (HHV) | |
| Electrolyzer efficiency | About 72 % (HHV) | |
| Tank inventory at 300 kPa gauge | About 7.9 L, 0.66 g | R5 met |
| Fuel cell | About 10.8 W net for about 29 min, 5.2 Wh | R4 met |
| Round trip | About 25 % (HHV basis) | Near the low end of the published 27.4 to 48 % range |
| Full release into a 30 m³ room | About 0.03 % by volume, under 1 % of LFL | R7 met |
| Hydrogen measurement uncertainty | About ±2 % | R1 expected met |
| Bench size and mass | 900 x 450 mm, about 770 mm tall, about 18 kg | R13 met |
| Parts cost (H2Guard excluded) | About $845, or about $780 without the bench supply | **R14 not met** |

Requirements not met or at risk:

- **R14 (cost) not met:** about $845 against $450. The two stacks (about $400 together) and the pressure parts drive the cost.
- **R9 (hydrogen purity) not met on paper:** the 12 W class fuel cell specifies 99.995 % or better; the purity after the separator and drier is unknown.
- **R10 (electrolyzer back-pressure) at risk:** a generic stack must be confirmed to hold 300 kPa gauge on the hydrogen side.
- **R8 (interlock) at risk:** depends on H2Guard, whose README is still at scaffold stage; set point and response time are not yet defined.

### Proposed, awaiting Amish (items 1 to 9 now Decided by Amish, 2026-09-25: go with recommendation, HBN-DDR-002)

1. **Budget.** Options: (a) raise `budget_usd` to about $850 (bench power supply included, H2Guard costed separately); (b) keep $450 as the bench-only cost with both stacks bought separately by the school; (c) shrink to a 5 W class fuel cell and a smaller electrolyzer, which cuts cost but weakens the measurements. Recommendation: (a). `project.yaml` is unchanged.
2. **Storage method.** Rigid 2 L tank at up to 300 kPa gauge (recommended), metal hydride canister, or near-atmospheric gasbag with a pump.
3. **PEM rather than alkaline electrolysis** (recommended, for student safety).
4. **Fuel cell source.** Generic 12 W class stack with a published polarization curve (recommended) or a branded stack at $482 to $576.
5. **Hydrogen measured by pressure, volume and temperature** rather than a mass flow meter (recommended).
6. **Bench power supply as the source**, with solar as a later option (recommended).
7. **H2Guard included in the kit price or not.** Recommendation: cost it separately but ship the two together.
8. **Tank kept above about 20 kPa gauge between lessons** with pressure-cycle purging of a new tank (recommended).
9. **First users.** Vocational technician training or secondary school practical first; recommendation: vocational training, where supervision and safety culture are stronger.

### Safety concerns

- Flammable gas with a very low ignition energy and a nearly invisible flame; the bench must never run without H2Guard detection, extraction and interlock.
- Pressure: 2 L at up to 300 kPa gauge (about 0.65 kJ of stored pressure energy); only rated metal vessels and fittings, relief at 350 kPa gauge piped into the hood, tank guard.
- Air ingress into the tank could form a flammable mixture inside a closed vessel; purge and minimum-pressure rules are part of the design.
- Oxygen and hydrogen outlets must stay separate.
- Mains-powered supply near water: earthed supply, RCD or GFCI, reservoir kept away from the supply.
- Warm stacks (about 20 W of heat each, fuel cell stack limit about 55 °C).
- Users include students under 18: supervised use only, with teacher-held control of the power supply.

### Problems and notes

- H2Guard's README is still the scaffold. H2Bench cites only what it states (sensor, relay controller, spark-free fan, normally closed supply valve, alarm). The interlock outputs H2Bench needs (power supply cut, tank solenoid close) should be confirmed with that project.
- Generic stack prices (items 6 and 12) could not be verified from a primary source; they are marked as estimates in the BOM.
- The Namibia figure in the README comes from a news report of a university statement, not a published study.
- The legacy `cad/src/model.py` placeholder is untouched (TRL 3 work).

### Recommended next step

Review this note and the media, then decide items 1, 2 and 9. If approved, run `/advance-trl3` to check the energy, gas law, uncertainty and release calculations in a CAL note, confirm electrolyzer back-pressure and purity with suppliers, and produce the parametric model and drawing sheet. The design is not ready for TRL 4.

## Session 2026-09-26: sources strengthened

README sources were checked with WebFetch and the weaker ones replaced or supported by primary or reputable secondary sources.

- **What sparked the idea:** Encyclopedia.com entry on William Robert Grove replaced by Grove's own paper, "On a gaseous voltaic battery," *Philosophical Magazine* 21 (1842): 417 to 420 (doi:10.1080/14786444208621600, metadata confirmed through Crossref). The 1843 *Philosophical Transactions* link now uses its DOI resolver, and the abstract confirms hydrogen and oxygen on platinum in dilute sulfuric acid and the decomposition of water. The unsupported phrase "the forerunner of the hydrogen fuel cell" was removed.
- **Namibia row:** Ecofin Agency replaced by *The Namibian* (21 September 2025), which quotes the NUST vice-chancellor on a talent gap of up to 130,000 workers by 2040, plus NUST's own IGNITE GH2 project page (685 graduates and 40 instructors).
- **Concept rationale:** the $482 to $576 fuel cell price now carries links to the two listings (Fuel Cell Shop, Fuel Cell Store).
- **Burning platform:** IEA skills survey wording corrected to match the source (some 700 energy companies, unions and training institutions).
- All other links (IEA Global Hydrogen Review 2025, European Commission, US DOE, PIB, IEA policy database for Chile, Oxford Institute for Energy Studies) were re-fetched and support their claims. No budget change.

## Session 2026-09-26: budget approved

Amish wrote, in chat on 2026-09-26: "i approve all the budget items." The open cost item (O5) is decided: budget set to $885 to cover the priced BOM (HBN-DDR-002 v0.2).

- `project.yaml` `budget_usd` $850 to $885; README budget and cost lines updated.
- R14 target $850 to $885; status **not met to met**, with no margin ($885 with the bench supply; $820 without; H2Guard excluded).
- Requirement counts (HBN-CAL-001 v0.3): 11 met, 1 not met (R9), 3 at risk, 1 not verifiable.
- Documents: HBN-PRB-001 v0.5, HBN-PRC-001 v0.5, HBN-REQ-001 v0.5, HBN-CAL-001 v0.3 (`sizing.py` budget constant 850 to 885, script re-run, `results.csv` regenerated), HBN-DDR-002 v0.2; `bom/bom-notes.md`; PDFs rebuilt. No media shows the budget, so none was regenerated.

## Session 2026-09-26: product appearance model and photoreal renders

Amish chose this repo for the first batch of product renders on 2026-09-26. This session adds an appearance model for photoreal renders; the render images (`media/render-hero.png`, `media/render-exploded.png`) are produced separately by the portfolio render step.

### What was done

- `cad/src/product_model.py` (new): `product_parts()` returns 116 parts (106 shell, 9 internal and the lab table top as context), each with a colour, a render material, its BOM line, a group and an explode offset. It imports `PARAMS`, `levels()`, `tank_cyl_len()` and `build_parts()` from `model.py`; the gas lines and the electrolyzer membranes are taken from `build_parts()` unchanged. It also defines `TITLE` and `RENDER_VIEWS` (hero, exploded and a front view from the student side).
- What it adds over the massing model:
  - Bench: T-slot grooves on the aluminium frame, a filleted HDPE deck and drip lip with a teal edge stripe and a name plate.
  - Back panel: the printed energy-chain schematic (flow line, seven stage nodes, captions), panel screws, a hydrogen warning sign, and lit logger and stage meter displays.
  - Canopy: clear polycarbonate sheet, aluminium edge trim, slotted posts with foot brackets, and a duct collar with a flange.
  - Components: a lab supply with lit voltage and current readouts, knurled knobs, binding posts and a switch; a HDPE reservoir with a teal cap and graduations; a clear deionizer cartridge showing its resin; teal electrolyzer end plates with tie rods, nuts, grooved titanium cells and brass ports; a clear separator (water visible) and a clear drier (indicator gel visible); a stainless arrestor with hex ends and a flow arrow; a brushed tank with a red shoulder band in a powder-coated guard; a brass manifold with a dial gauge, a red-capped relief valve, a needle valve knob and the cut switch; the regulator knob and solenoid coil; fuel cell plates, end plates, fan and finger guard; the electronic load with a lit readout and a lit lamp; and the H2Guard head, fan housing and controller with lit status lights.
  - Safety labels: a flammable gas label (GHS diamond) on the tank (wrapped), electrolyzer, regulator, fuel cell and H2Guard fan housing, and a warning sign on the back panel (BOM line 17).
- `README.md`: hero image now points to `media/render-hero.png`; an "Exploded render" link was added to the links line.
- Self-check previews (not in the repo) were made with the kit renderer; clear parts are left out of those previews.

### Differences from model.py (Proposed, awaiting Amish)

All main dimensions, positions and interfaces are as `model.py`. The differences are appearance only:

1. **Canopy edge trim and post foot brackets.** A 10 mm aluminium trim wraps the canopy edges and 6 mm foot brackets sit under the two posts; neither is in `model.py` or BOM line 3. Post extrusions stop 5 mm short of the canopy underside, inside the trim. Recommendation: adopt both in `model.py` at the next CAD update, since a bare 3 mm polycarbonate edge is hard to handle safely.
2. **Red shoulder band on the tank.** It follows the common convention of a red shoulder for flammable gas cylinders. Recommendation: keep it for the render, and confirm the marking against the vessel supplier's standard before any purchase.
3. **Product colours in place of the concept palette.** Examples: the load and lamp are light grey rather than yellow; the meters are black with lit readouts rather than green; H2Guard is white with a teal band rather than red. Recommendation: use the product palette for renders and keep the concept palette for the numbered concept media, where the colours help the callouts.
4. **Detail inside the model.py envelopes.** The lamp is a holder with a bulb, and the fuel cell has end plates and a fan guard. The separator and drier are clear bodies with end caps, and the tank has a 5 mm base fillet sitting in a shallow recess in the cradle. All stay inside the model.py envelopes. Recommendation: accept as appearance only.
5. **Context.** A 1,020 x 560 mm section of the existing lab table top replaces the full table and the 1.75 m person, so the bench fills the frame. Recommendation: accept for product renders; the concept hero keeps the person for scale.

### Status

This is an appearance model only: no tolerances, no fabrication detail, no PCB layouts. `trl` stays 3 and TRL 4 remains on hold. No change to `model.py`, the BOM, the budget or any requirement status. Safety concerns are unchanged from the sessions above.

## Session 2026-09-27: kit 1.5.0 and image quality

- Kit 1.5.0 synced: STANDARDS v1.5 (sections 12 to 15: product renders, storefront images and image quality, public release, authorship and signing), `.kit/cards.py`, `.kit/image_qc.py`, `.kit/release_gate.py`, issue templates, and the `/render-product` and `/release` commands. `CLAUDE.md` now matches `.kit/CLAUDE.md`.
- Every `media/render-*.png` recaptioned from its original render with the new layout: the title, concept label and repository sit in a band above the render and the view note in a band below it, each line wrapped to the image width, so no text overlaps other text or the render or runs off the image. `media/card.png` and `media/social-preview.png` regenerated with the same rules.
- `python .kit/image_qc.py` and `python .kit/release_gate.py` pass. trl stays 3.

## Session 2026-10-02: open decisions decided

Amish, 2026-10-02: "i approve your recommendations for all 555 open decisions." This approves the recommendation written for every open decision in the design decisions register (HBN-DEC-001). trl stays 3; nothing was built, bought or tested, and TRL 4 remains on hold.

### Decisions recorded (8)

| Register item | Decision |
| --- | --- |
| 1 | HBN-DDR-003 accepted as made: P1 to P13 and their knock-on changes |
| 2 | Bench supply ships in the kit but sits beside the bench; 10 mm deck; about 24.2 kg with an aluminium tank |
| 3 | Separator drained by hand by the teacher at 20 kPa gauge, under the hood, with H2Guard running |
| 4 | Catalytic deoxidizer fitted between separator and drier now; removed only on supplier evidence of oxygen within 99.995 % |
| 5 | Proposal to H2Guard: 24 V normally closed solenoid powered from H2Guard; alarm contact in series with the 310 kPa cut relay; 60 m³/h hood extraction stated separately; vocational technician training as shared first user |
| 6 | Tank: certified aluminium cylinder (6061-T6 class), about 2 L, stamped 1 MPa or more, threaded neck; stainless only at about 1.0 kg or less |
| 7 | First worksheets for post-16 vocational hydrogen or renewable energy technician courses |
| 8 | Instructor-run class demonstration first; group practicals after a recorded run of attended fills with H2Guard tested before each |

All 8 moved to Decisions made in HBN-DEC-001, dated 2026-10-02; the Open decisions section now reads "None."

### Documents changed

- `docs/06-design-decisions.md` (HBN-DEC-001 v0.2): items 1 to 8 moved to Decisions made; Open decisions reads "None"; two earlier rows now point to the decisions; the bench-supply saving in Value engineering reworded, since it would reverse D10
- `docs/decisions/0003-design-for-construction.md` (HBN-DDR-003 v0.2): status accepted (kept Draft); A1 and A2 marked accepted; consequence added
- `docs/03-requirements.md` (HBN-REQ-001 v0.7): R13 restated for the bench as moved (supply beside it); R9 and R8 status note the decided deoxidizer and the H2Guard proposal; statuses unchanged until the model follows
- `docs/04-calcs/01-sizing.md` (HBN-CAL-001 v0.5): decisions noted under R8, R9 and R13; figures unchanged
- `docs/02-concept.md` (HBN-PRC-001 v0.7): open questions answered (deoxidizer, tank, worksheets, H2Guard proposal); safety notes for the separator drain and demonstration first
- `docs/01-problem.md` (HBN-PRB-001 v0.7): curriculum and first use decided
- `docs/05-build-plan.md` (HBN-BLD-001 v0.2): section 2 says HBN-DDR-003 is accepted; separator drain rule added to the bought parts
- `bom/bom-notes.md`: tank material, deoxidizer, 10 mm deck and the 24 V solenoid proposal noted, not yet in BOM lines or prices
- `README.md`: purity and mass decisions noted
- `docs/decisions/0001-trl2-review-decisions.md` (HBN-DDR-001 v0.3): item 12 ("Proposed, awaiting Amish") recorded as decided
- `docs/decisions/0002-recommendations-accepted.md` (HBN-DDR-002 v0.3): items O1 to O4 (awaiting Amish) recorded as decided
- PDFs regenerated with `python3 .kit/render.py`; superseded versions removed.

### Follow-up actions to carry approved decisions into the design

The model, BOM quantities and prices, calculations and pictures were not changed in this session. These actions carry the approved decisions into them:

1. Decision 2 (model, drawings, build plan pictures): Change the deck from 12 to 10 mm in `cad/src/model.py`, re-run the constructability checks, and regenerate HBN-DWG-001, the deck making sketch and the step pictures; show the bench supply beside the bench, not on the deck.
2. Decision 2 (BOM, calculations): Reprice the deck (BOM line 2) and recompute mass in `docs/04-calcs/sizing.py` (expected about 24.2 kg for the bench without its supply), then set R13's status from the result.
3. Decision 4 (model, BOM, calculations, build plan pictures): Add the catalytic deoxidizer between the separator and the drier: model, line routing and constructability checks, a BOM line with price, mass in the calculation, and the build plan step and pictures for section 3.10.
4. Decision 4 (documents): Ask the stack supplier for oxygen in the hydrogen at the bench's lowest operating current; add oxygen crossover as a tank safety item to HBN-CAL-001 section 8.
5. Decision 5 (cross-repo, BOM, build plan pictures): Send the interface proposal to H2Guard; once agreed, change the tank solenoid to 24 V normally closed (BOM line 11 and price), and redraw the interlock wiring diagram with the alarm contact in series with the 310 kPa cut relay.
6. Decision 6 (BOM, model): Name the certified aluminium cylinder in BOM line 9 (replacing "aluminium or stainless") and confirm its diameter, base and neck thread against the cradle pocket and manifold adapter.
7. Decision 7 and 8 (documents): Write the first worksheets for post-16 vocational technician courses as an instructor-run demonstration, with the record of attended fills that must precede group practicals.

### Points found in the review

Raised when the recommendations were written (2026-10-01) and kept here so they are not lost:

- Value engineering: the savings list proposes letting the school supply the bench power supply (USD 85), which would reverse your decision to put the supply in the kit (HBN-DDR-002, D10). The 'without the bench supply' cost (USD 934, USD 49 over) does not compare like with like, because the USD 885 target was set with the supply included.
- Item 4 (purity) is framed only as fuel cell ageing; oxygen crossover into the stored hydrogen is also a safety question for the tank and is not discussed in HBN-CAL-001 section 8.
- Item 5: the 60 m³/h hood extraction and H2Guard's 150 m³/h room exhaust are different quantities, so the register presents them as a mismatch when they may both be right.
- Item 5 lists 'first user' as open with H2Guard, but H2Bench's first user is already decided (HBN-DDR-001, item 8); only H2Guard's side is open.
- The mass calculation (HBN-CAL-001 section 9) prices the tank shell as aluminium (0.80 kg at 3 mm wall) while the tank material is still open (item 6) and BOM line 9 says 'aluminium or stainless'; a stainless tank at the same wall would add about 1.6 kg.

## Session 2026-10-02: approved follow-ups carried out

Amish approved all follow-up actions from the open-decision sign-off (2026-10-02). trl stays 3; nothing was built, bought or tested.

### Follow-ups

| No. | Follow-up | Status |
| --- | --- | --- |
| 1 | 10 mm deck in the model, constructability checks re-run, HBN-DWG-001, deck making sketch and step pictures redrawn; supply shown beside the bench | Done. 144 checks pass. HBN-DWG-001 is Rev P4 |
| 2 | Deck repriced, mass recomputed, R13 set from the result | Done. Deck USD 3 less; 24.4 kg for the bench as moved (27.4 kg with the supply); R13 met |
| 3 | Catalytic deoxidizer between separator and drier: model, routing, checks, BOM line, mass, build plan step and pictures | Done. BOM line 19, USD 60 (estimate, no quote); 0.16 kg; build plan section 3.9 joint 7, step 8, step 12 and the piping picture |
| 4a | Add oxygen crossover as a tank safety item to HBN-CAL-001 section 8 | Done (HBN-CAL-001 v0.6, sections 8 and 13) |
| 4b | Ask the stack supplier for oxygen in the hydrogen at the lowest operating current | Not done: outreach by Amish. R9 stays at risk until the figure arrives |
| 5 | Send the interface proposal to H2Guard; change the solenoid to 24 V normally closed; redraw the interlock wiring | Not done: outreach by Amish, and the solenoid change waits for H2Guard to agree. BOM line 11 stays 12 V. The wiring picture already shows the alarm contact in series with the 310 kPa cut relay |
| 6 | Name the certified aluminium cylinder in BOM line 9 and confirm diameter, base and neck against the cradle and manifold adapter | Done for diameter and base (106 to 111 mm base for the 112 mm pocket, 10 mm deep). Neck thread cannot be confirmed until a supplier is chosen; no catalogue part is named |
| 7 and 8 | First worksheets for post-16 vocational technician courses, with the record of attended fills | Not done: teaching and trial material that follows the TRL 4 build and a partner college |

### Requirement and figure changes

- R9: not met to at risk (deoxidizer fitted; residual oxygen 10 to 200 ppm at an assumed 99 % conversion against 50 ppm; no supplier data).
- R13: at risk to met (24.4 kg for the bench as moved; 900 x 450 x 753 mm).
- R14: USD 1056 against the USD 885 value-engineering target (USD 171 over); USD 991 without the supply, USD 971 without supply and RCD. `budget_usd` unchanged.
- Eleven requirements met, three at risk (R8, R9, R10), R16 not verifiable at TRL 3.

### Documents changed

- `cad/src/model.py`, `cad/step/`, `cad/stl/`: 10 mm deck, supply beside the bench, deoxidizer and its clip; 144 checks.
- `bom/bom.csv` (lines 1, 9 and 19), `bom/bom-notes.md`.
- `docs/04-calcs/sizing.py`, `results.csv`, `01-sizing.md` (HBN-CAL-001 v0.6).
- `docs/03-requirements.md` (HBN-REQ-001 v0.8), `docs/02-concept.md` (HBN-PRC-001 v0.8), `docs/06-design-decisions.md` (HBN-DEC-001 v0.3), `docs/decisions/0003-design-for-construction.md` (HBN-DDR-003 v0.3), `docs/05-build-plan.md` (HBN-BLD-001 v0.3), `README.md`.
- Pictures: `cad/drawings/HBN-DWG-001` (Rev P4), the making sketches, all build plan joint, step, overview, piping and wiring pictures, and the concept media (hero, blueprint, cutaway, exploded, flow, model.glb).
- `cad/src/product_model.py` follows the model (deck, supply beside the bench, deoxidizer). Render scenes for the hero, front and exploded views exported to `/home/claude/renders/h2bench`; photoreal renders, card and social preview are made on Amish's Mac.

### Cross-repo actions

- H2Guard: receive the interface proposal (24 V normally closed solenoid powered from H2Guard, alarm contact in series with the 310 kPa cut relay, 60 m³/h hood extraction stated apart from the 150 m³/h room exhaust, vocational technician training as shared first user).
- Stack supplier (outside the portfolio): oxygen in the hydrogen at the lowest operating current.

## 2026-10-02: photoreal renders redone on the constructable design

Rendered with Blender Cycles on Amish's Mac from the updated appearance model; captioned with `.kit/photo_caption.py`; `media/card.png` and `media/social-preview.png` regenerated with `.kit/cards.py`. Views: hero, exploded, front. image_qc passes. Appearance deviations are those logged above as proposed, awaiting Amish.

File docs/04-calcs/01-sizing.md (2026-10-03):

---
doc_id: HBN-CAL-001
title: H2Bench sizing calculations
project: H2Bench
doc_type: Calculation note
version: "0.6"
status: Draft
date: '2026-10-02'
author: Amish Chadha
license: CERN-OHL-S-2.0
revisions:
- version: "0.1"
  date: '2026-09-25'
  author: Amish Chadha
  change: First TRL 3 sizing note (electrolyzer and fill, inventory and pressure, fuel cell, energy balance, measurement uncertainty, hood and venting, interlock, water and drier, envelope and mass, cost, logging)
- version: "0.2"
  date: '2026-09-25'
  author: Amish Chadha
  change: Recommendations accepted by Amish (DDR-002)
- version: "0.3"
  date: '2026-09-26'
  author: Amish Chadha
  change: Budget approved by Amish ($885); R14 from not met to met
- version: "0.4"
  date: '2026-10-01'
  author: Amish Chadha
  change: Constructable design (HBN-DDR-003); mass from the model's parts, cost against the value-engineering target, guard clearance corrected
- version: "0.5"
  date: '2026-10-02'
  author: Amish Chadha
  change: "Decisions of 2026-10-02 noted under R8, R9 and R13; figures unchanged until the model and sizing.py are updated"
- version: "0.6"
  date: '2026-10-02'
  author: Amish Chadha
  change: "Decisions of 2026-10-02 carried into the model and sizing.py: 10 mm deck, supply beside the bench, deoxidizer (line 19), aluminium tank; R13 met, R9 at risk, cost USD 1056; oxygen crossover added as a tank safety item in section 8"
---

# H2Bench sizing calculations

On paper, H2Bench meets eleven of its sixteen requirements, and cost (R14) is reported against its value-engineering target. **Three are at risk**: the H2Guard interlock (R8), hydrogen purity at the fuel cell (R9, now with a catalytic deoxidizer fitted but no supplier data) and electrolyzer back-pressure (R10, 332 kPa). Mass (R13) is met at 24.4 kg for the bench as moved. Value-engineering target USD 885; estimated cost of the constructable design USD 1056 (USD 171 over the target). Version 0.6 carries the decisions of 2026-10-02 into the model: the deck is 10 mm, the bench supply stands on the lab table beside the bench, a catalytic deoxidizer (BOM line 19) sits between the separator and the drier, and the tank is a certified aluminium cylinder. Mass falls from 28.0 to 27.4 kg with the supply (24.4 kg for the bench as moved), cost rises from USD 999 to USD 1056, R9 moves from not met to at risk and R13 from at risk to met. Version 0.4 follows the constructable design of HBN-DDR-003: the four posts, top frame, mounts and water lines added for construction raise the mass from 25.3 to 28.0 kg and the cost from USD 885 to USD 999; the made parts are now weighed from their model volumes; and the guard clearance is corrected from 18 to 50 mm. No energy, gas, pressure or venting figure changes. In v0.3, R14 was counted as met against the USD 885 budget; it is now reported as over or under the value-engineering target. Version 0.2 applies the decisions Amish accepted on 2026-09-25 (HBN-DDR-002): the relief valve moves from 350 to 325 kPa gauge, which brings R5 from at risk to met (full-lift inventory 10.5 L to 9.9 L); a pressure switch cuts the electrolyzer supply at 310 kPa gauge, so the relief valve is a backup only; and `budget_usd` rises from $450 to $850 with the bench supply in the kit. The switch and its relay add $20 and 0.15 kg. Setup time (R16) needs hardware to verify. The TRL 2 energy numbers hold: a 17.7 min fill and a 29.0 min discharge return 5.2 Wh of 20.8 Wh, a round trip of 25.1 % on the HHV basis, and students can measure each stage to within 1.8 %.

Every number here is printed by `docs/04-calcs/sizing.py` (run from the repo root: `python docs/04-calcs/sizing.py`), which also writes `docs/04-calcs/results.csv`. The script reads the tank and bench dimensions and the made parts' volumes from `cad/src/model.py` and the costs from `bom/bom.csv`. All values are first-principles estimates; nothing is measured.

## 1. Assumptions

*Table 1. Inputs. All are assumptions for a paper design.*

| Input | Value | Basis |
| --- | --- | --- |
| Gas constants | R = 8.314 J/(mol K), F = 96,485 C/mol, 24.05 L/mol at 20 °C and 101.3 kPa; H2 HHV 285.83 kJ/mol, LHV 241.83 kJ/mol, γ = 1.41 | Standard values; ideal gas, with a 0.24 % compressibility correction noted at 400 kPa absolute |
| Electrolyzer | 4 cells, 1.95 V per cell, 9 A, Faraday efficiency 95 %; 2.20 V per cell at end of life | HBN-PRC-001; generic 56 cm² class cells |
| Tank | 2.000 L internal (inner radius 52 mm, 200.8 mm straight, hemispherical top), 3 mm wall; certified aluminium cylinder (6061-T6 class), decided 2026-10-02 | `cad/src/model.py` |
| Gas volume outside the tank at tank pressure | 0.15 L (separator headspace, drier, lines) | Estimate |
| Pressures | Fill 70 to 300 kPa gauge; supply cut by a pressure switch at 310 kPa gauge; relief 325 kPa gauge with 10 % overpressure at full lift; check valve 7 kPa; kept at 20 kPa gauge overnight | HBN-PRC-001 v0.4, HBN-DDR-002, typical relief valve |
| Temperatures | Lab 20 °C; coldest 15 °C; separator gas 25 °C | HBN-PRB-001 |
| Storage loss | 2 % of the hydrogen made per cycle | Estimate, to be measured |
| Fuel cell | 13 cells, 0.60 V at 1.5 A (7.8 V, 11.7 W), fuel utilization 95 %, 0.9 W fan and controls; 0.18 L/min at full output; 45 to 55 kPa gauge supply; 99.995 % purity | Listing for the 12 W class ([Fuel Cell Store](https://www.fuelcellstore.com/horizon-12-watt-pem-fuel-cell), checked 2026-09-25) |
| Measurement | Transducer 0.25 % of 600 kPa full scale; thermistor ±1 K; tank volume ±1 % by water fill; power ±1 % | HBN-REQ-001 R1 |
| Room and hood | 30 m³ room; 60 m³/h through the canopy duct | Assumed hood share of H2Guard's 150 m³/h continuous exhaust (HGD-PRC-001) |
| H2Guard | Warning 0.4 % vol (10 % LFL), trip 1.0 % vol (25 % LFL); trip to valve closed 1.1 s | HGD-REQ-001 R2 to R4, HGD-PRC-001 (TRL 2 estimates) |
| Drier | 50 g silica gel, 10 % usable water uptake | Typical indicating gel at low humidity |
| Value-engineering target | USD 885 (`budget_usd`), bench supply included, H2Guard excluded; a hypothetical control target, not a limit | HBN-DDR-002; Amish, 2026-10-01 |

## 2. Electrolyzer and fill (R2, R3, R10)

The stack draws 7.8 V x 9 A = **70.2 W** (79 W with aged cells at 2.20 V), inside the 100 W limit (R3) and the 30 V, 10 A supply. Faraday's law gives 1.772 x 10⁻⁴ mol/s, or **256 mL/min** at 20 °C. Filling the 2.000 L tank from 70 to 300 kPa gauge takes 0.1887 mol (4.54 L at 20 °C and 101.3 kPa), so the fill lasts **1,065 s (17.7 min)** and uses **20.77 Wh**. The hydrogen holds 14.99 Wh (HHV): an electrolyzer efficiency of **72.2 %** (voltage efficiency 75.9 %, Faraday efficiency 95 %). The stack gives off about 19.5 W of heat.

The electrolyzer compresses its own hydrogen. The Nernst term at 300 kPa gauge is **17.4 mV per cell**, 0.89 % of the cell voltage, so no compressor is needed.

**Back-pressure (R10).** The membrane must hold the tank pressure plus the check valve cracking pressure over the oxygen side: **307 kPa** in normal filling and **317 kPa** at the 310 kPa gauge supply cut. The supply cut stops the stack before the relief valve can lift, so the relief is a backup only; if the cut failed, the membrane would see **332 kPa** at the 325 kPa gauge relief setting and 365 kPa at full lift. R10 is restated as 332 kPa or more (HBN-REQ-001 v0.4, was 300 kPa). No generic stack rating is in hand. At risk.

## 3. Inventory and pressure (R5, R6, R7)

*Table 2. Hydrogen held, expressed at 20 °C and 101.3 kPa.*

| State | Hydrogen |
| --- | --- |
| Tank at 300 kPa gauge | 0.3293 mol, 7.92 L, 0.664 g |
| Tank and lines at 300 kPa gauge | 8.52 L |
| Tank and lines at relief set, 325 kPa gauge | 9.05 L (9.20 L at 15 °C) |
| Tank and lines at full relief lift (358 kPa gauge) and 15 °C | **9.90 L** |

The TRL 2 note gave 7.9 L "at the relief setting"; that is the tank alone at the working pressure. With the relief at 350 kPa gauge (v0.1) the full-lift case on a cold day was 10.5 L. A relief set at 329 kPa gauge or less keeps even that case under 10 L, and 325 kPa gauge is now decided (HBN-DDR-002): 9.0 L at the relief set point and **9.9 L** at full lift and 15 °C. **R5 is met**, with a 0.1 L margin in the worst case.

**Pressure parts (R6).** Working 300 kPa gauge, supply cut 310 kPa gauge, relief 325 kPa gauge. The modeled vessel (110 mm outside diameter, 3 mm aluminium wall) has a hoop stress of 17.8 MPa at its 1 MPa rating and 71.3 MPa at four times that, against a 6061-T6 yield of 276 MPa. Stored pressure energy is **646 J** at 300 kPa gauge (710 J at the 325 kPa gauge relief setting), by isentropic expansion to atmosphere. Stored chemical energy is 94 kJ (HHV), 80 kJ (LHV). Met.

**Room release (R7).** The relief-set inventory mixed into a 30 m³ room gives **0.030 % by volume, 0.75 % of the lower flammable limit**; the worst case is 0.033 %. Met by a wide margin. H2Guard's proposed inventory rule (1 % of room volume, 300 L for 30 m³, HGD-REQ-001 R9) is met thirtyfold.

## 4. Fuel cell and discharge (R2, R4)

Thirteen cells at 0.60 V and 1.5 A give **11.7 W gross and 10.8 W net** after 0.9 W for the fan and controls, which meets R4 with a 0.8 W margin. At 0.58 V per cell the net is 10.4 W; at 0.55 V it falls to 9.8 W, below target. The stack reacts 146 mL/min and, at 95 % utilization, draws **154 mL/min**, inside the listed 0.18 L/min at full output. (The TRL 2 table's 146 mL/min was the reacted flow.)

After 2 % storage loss, 0.1850 mol is available, which runs the fuel cell for **1,739 s (29.0 min)** and delivers **5.22 Wh**. Net fuel cell efficiency is 35.5 % (HHV) or 42.0 % (LHV), consistent with the 40 % system efficiency listed for the 12 W class. About 18.7 W of heat and purge loss leaves the stack. The full cycle runs for **46.7 min**, inside the 60 min of R2. Met.

## 5. Energy balance

*Table 3. Energy per lesson cycle, HHV basis. These values drive `media/flow.png`.*

| Stage | Energy | Loss |
| --- | --- | --- |
| Electricity in | 20.8 Wh | |
| Hydrogen made | 15.0 Wh | Electrolyzer heat 5.8 Wh |
| After storage | 14.7 Wh | Leaks and purges 0.3 Wh |
| Fuel cell net DC | 5.2 Wh | Fuel cell heat, purge and fan 9.5 Wh |

The round trip is **25.1 %** (HHV basis), just below the 27.4 to 48 % range published for power-to-hydrogen-to-power ([Oxford Institute for Energy Studies, 2025](https://www.oxfordenergy.org/wpcms/wp-content/uploads/2025/07/ET48-Power-to-Hydrogen-to-Power.pdf)), as expected at 12 W scale. Each fill splits 3.40 g of water and vents 2.27 L of oxygen.

## 6. Measurement uncertainty (R1)

Hydrogen is counted from pressure and temperature before and after each stage: n = PV/(RT).

*Table 4. Standard uncertainty (k = 1) of the hydrogen made per fill.*

| Source | Contribution |
| --- | --- |
| Pressure, 1.5 kPa per reading, two readings | 0.92 % |
| Temperature, ±1 K, two readings | 0.65 % |
| Tank volume, ±1 % | 1.0 % |
| Combined | **1.51 %** |

The thermistor is bonded to the tank wall, so the gas temperature matters. During the fill the flow work into the tank heats the gas about 0.95 K above the wall, and the gas settles to the wall with a 15 s time constant; readings are taken 2 min after the fill ends. With power measured to ±1 %, the stage efficiencies carry: electrolyzer 1.8 %, storage 1.0 %, fuel cell 1.8 %, round trip 1.4 % and Faraday efficiency 1.8 %. All are within the ±5 % of R1. Met.

## 7. Hood, venting and interlock (R8, R15, R16)

**Hood.** At 60 m³/h (1,000 L/min) the 100 mm duct runs at 2.12 m/s. The electrolyzer's full output leaking into the hood gives only 0.026 % by volume at the duct. A leak must exceed 4.0 L/min to reach H2Guard's warning at the duct and 10 L/min to trip it. Small leaks are diluted by the extraction; the sensor at the high point catches large ones and a stopped fan (HGD-REQ-001 R5).

**Venting.** Venting the tank and lines from 300 to 20 kPa gauge releases 5.94 L. A needle valve set for 3.0 min (an effective orifice of about 0.16 mm) gives a peak of 3.50 L/min, or 0.35 % by volume at the duct (8.7 % of LFL), just under H2Guard's 0.4 % warning. At a constant flow, a vent shorter than 89 s would reach the warning. The end-of-day vent after a discharge (70 to 20 kPa gauge) is only 1.06 L. The 3.0 min vent meets the 5 min shutdown part of R16; setup time needs a walk-through with hardware, so **R16 is not verifiable at TRL 3**.

**Interlock (R8).** From H2Guard's TRL 2 figures, the trip reaches a closed valve and a dead supply in about 1.1 s (comparator and relay 0.1 s, solenoid 1.0 s), inside 2 s; the electrolyzer makes only 4.7 mL of hydrogen in that time. But H2Guard is itself at TRL 2, its valve is a 24 V part while H2Bench's tank solenoid is 12 V, and whether its relay can break the 9 A DC supply line is not specified. **At risk.** On 2026-10-02 Amish decided to propose to H2Guard a 24 V normally closed tank solenoid powered directly from H2Guard, its alarm contact in series with the 310 kPa cut relay, and 60 m³/h stated as the hood extraction rate, separate from H2Guard's 150 m³/h room exhaust.

**Guard (R15).** The four guard rods stand at the corners of a 156 mm square, so each clears the tank shell by 50 mm (v0.3 gave 18 mm, measured as if the rods stood on the axes); the top plate stops the tank lifting and the cradle pocket stops it tipping. The relief and vent lines run to the outlet hanger under the canopy in the model. Met by design review.

## 8. Water, drier and purity (R9, R11)

Gas leaving the separator at 25 °C carries 0.79 to 1.85 % water vapour by mole, depending on tank pressure: about 0.045 g of water per fill. 50 g of silica gel at 10 % uptake lasts about **110 fills** before its color changes. The drier removes water, but PEM stacks also pass some oxygen across the membrane, and the fuel cell listing asks for 99.995 % or better, which is 50 ppm of all impurities together. On 2026-10-02 Amish decided to fit a catalytic deoxidizer between the separator and the drier (BOM line 19, USD 60, 0.16 kg), and to remove it only if the stack supplier's data show oxygen within the 99.995 % limit at the bench's lowest operating current. The cartridge reacts oxygen with hydrogen to water over a palladium catalyst. Because the crossover is unknown, three cases are run: at 0.1, 0.5 and 2.0 % oxygen in the hydrogen, the cartridge reacts 0.26, 1.28 and 5.12 mL/min of oxygen, warms by 0.09, 0.43 and 1.71 W, and forms 7, 34 and 136 mg of water per fill (the drier takes 5 g). At an assumed 99 % conversion the residual oxygen is 10, 50 and 200 ppm, so the limit is met only at the low end; **R9 is at risk**, not met, until the supplier gives the oxygen figure and the cartridge's conversion. Action: ask the stack supplier for oxygen in the hydrogen at the bench's lowest operating current (outreach by Amish, open).

**Oxygen crossover as a tank safety item.** Oxygen in the stored hydrogen is a safety question for the tank as well as a purity question for the fuel cell. A hydrogen and oxygen mixture is flammable over a wide range, with a lower limit of about 4 % oxygen in hydrogen (handbook value, to confirm), and the tank is a closed vessel at up to 325 kPa gauge with a pressure energy of 710 J at relief. At 2.0 % crossover before the deoxidizer the mixture is within a factor of two of that limit; after a 99 % conversion it is 0.02 %, far below it. The deoxidizer is therefore the barrier that keeps the tank gas outside the flammable range, and it must not be removed on a purity argument alone: removal should wait for the supplier's oxygen figure at the lowest operating current, and the margin below the 4 % limit at the tank is for Amish to set (proposed: at least tenfold). The check valve and flame arrestor sit after the deoxidizer and the drier, so a flame cannot travel back into the stack. Until the figure is in hand, the operating rules stay: pressure 300 kPa gauge or less, guard in place, H2Guard running.

Water quality (R11) is met by the mixed-bed resin and conductivity check.

## 9. Envelope and mass (R13)

The model's envelope above the lab table is **900 x 450 x 753 mm**, inside 1,000 x 500 x 800 mm.

*Table 5. Mass estimate. Made parts are weighed from their volumes in `cad/src/model.py` (aluminium 2,700 kg/m³, HDPE 950 kg/m³, polycarbonate 1,200 kg/m³, extrusion 0.5 kg/m); bought parts use typical catalogue masses.*

| Item | Mass (kg) |
| --- | --- |
| 1 Frame (3.44 m of extrusion, 8 brackets), deck (10 mm, notched), drip lip | 1.88 + 3.81 + 0.12 |
| 2 Back panel, 3 mm aluminium composite, 900 x 550 mm | 1.88 |
| 3 Posts and top frame (4.65 m of extrusion, 14 brackets) | 2.60 |
| 3 Canopy, duct collar and outlet hanger | 1.30 |
| 4 Bench power supply (stands beside the bench, not on it) | 3.00 |
| 5 Reservoir (filled), deionizer, stand, water post and clips | 0.80 + 0.29 |
| 6 Electrolyzer stack and feet | 3.00 + 0.06 |
| 7 Separator, drier, column bracket and clips | 0.40 + 0.17 |
| 19 Catalytic deoxidizer cartridge and clip (assumed) | 0.16 |
| 8 Check valve, arrestor, saddle and clip | 0.32 |
| 9 Tank shell (aluminium, from the model); cradle, guard rods, nuts and top plate | 0.80 + 1.31 |
| 10 and 11 Manifold with cut switch, regulator and solenoid | 1.30 |
| 12 Fuel cell (275 g listed) with controller, and its bridge | 0.40 + 0.06 |
| 13 and 14 Load, lamp, meters, display and cut relay | 0.75 |
| 15 H2Guard parts on the bench | 1.50 |
| 16 and 17 Tubing (gas and water lines), wiring, fasteners and T-nuts | 1.50 |
| Total | **27.4** (24.4 for the bench as moved, without the supply) |

The envelope footprint is unchanged and the height falls from 755 to 753 mm with the 10 mm deck. The mass was 28.0 kg with the supply at v0.5 (the rear posts, top frame and brackets added about 2.4 kg to the 25.3 kg of v0.3). The decisions of 2026-10-02 change it: the 10 mm deck saves 0.77 kg, the deoxidizer adds 0.16 kg, and the bench supply stands beside the bench, so the bench as moved is **24.4 kg**, inside the 25 kg limit with 0.6 kg to spare; with the supply it is 27.4 kg. **R13 is met**, provided the tank stays aluminium: a stainless tank of the same wall would add about 1.6 kg and break the limit (stainless is allowed only at about 1.0 kg or less, HBN-DEC-001).

## 10. Cost (R14)

Value-engineering target: USD 885 (`budget_usd`, a hypothetical control target, not a limit; Amish, 2026-10-01). Estimated cost of the constructable design: USD 1056 (USD 171 over the target), H2Guard excluded. Without the bench supply it is USD 991 (USD 106 over), and without the supply and the plug-in RCD USD 971 (USD 86 over). Since v0.5 the catalytic deoxidizer (BOM line 19) adds USD 60 (an estimate with no quote: a small palladium cartridge, two compression fittings and a clip) and the 10 mm deck saves USD 3 (HDPE sheet bought by weight at about USD 4 per kg, 3.80 kg against 4.57 kg), so USD 999 becomes USD 1056. The parts added for construction (HBN-DDR-003) account for USD 114 of the rise from USD 885, across BOM lines 1, 3, 5, 6, 7, 8, 9, 12, 16 and 17. The two stacks with their mounts are USD 408, 39 % of the total. The main cost drivers and the savings worth trying are in the design decisions register (HBN-DEC-001, Value engineering).

## 11. Logging (R12)

One cycle is 2,804 s, so a 1 Hz log with 10 channels is 2,804 rows, about 224 kB of CSV. Met by design review.
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

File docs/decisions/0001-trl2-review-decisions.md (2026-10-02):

---
doc_id: HBN-DDR-001
title: H2Bench TRL 2 review decisions
project: H2Bench
doc_type: Design decision record
version: "0.3"
status: Draft
date: '2026-10-02'
author: Amish Chadha
license: CERN-OHL-S-2.0
revisions:
- version: "0.1"
  date: '2026-09-25'
  author: Amish Chadha
  change: Record the TRL 2 review items adopted for TRL 3 work under Amish's 2026-09-25 instruction, and the items that remain open
- version: "0.2"
  date: '2026-09-25'
  author: Amish Chadha
  change: Recommendations accepted by Amish (DDR-002)
- version: "0.3"
  date: '2026-10-02'
  author: Amish Chadha
  change: "Item 12 decided by Amish on 2026-10-02 (HBN-DEC-001)"
---
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

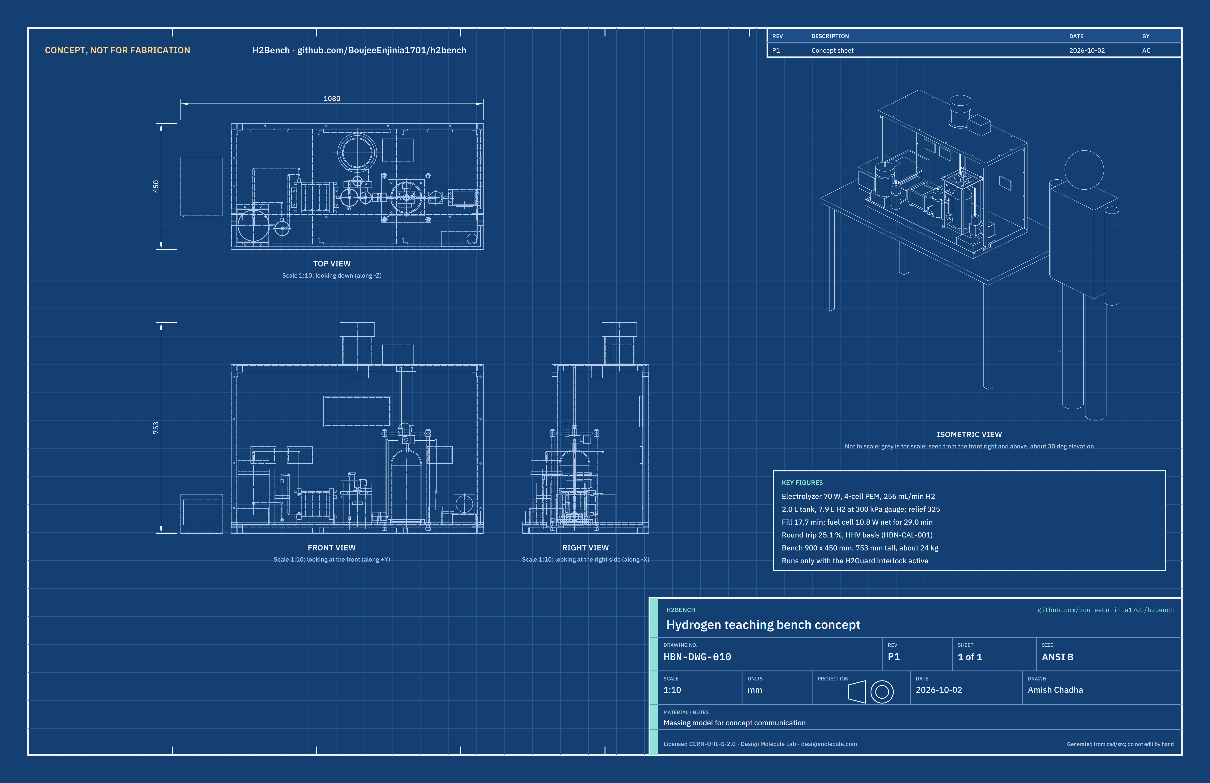
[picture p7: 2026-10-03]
media/concept-blueprint.png

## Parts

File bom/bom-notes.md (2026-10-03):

# BOM notes

- Rows 1 to 15 and 19 are numbered to match the callouts in `media/exploded.png`. Rows 16 to 18 are not numbered in the exploded view; the gas lines of row 16 are modelled as 6 mm tubes.
- Every line is priced. All prices are indicative USD figures for a single prototype in 2026, not quotes. Items 6, 9 and 12 are estimates for generic parts and carry the largest uncertainty. The branded 12 W fuel cell list price ($576) and the MSE 300 mL/min single-cell stack price ($1,396.95) were checked on 2026-09-25.
- Totals (checked by `docs/04-calcs/sizing.py`, HBN-CAL-001 v0.6 section 10): **USD 1056** for all 19 lines; USD 991 without the bench power supply (line 4); USD 971 if the bench socket is also already RCD protected (line 18).
- Value-engineering target: USD 885 (`budget_usd`, a hypothetical control target, not a limit; Amish, 2026-10-01). Estimated cost of the constructable design: USD 1056 (USD 171 over the target). The main cost drivers and savings worth trying are in the design decisions register (`docs/06-design-decisions.md`).
- Lines 1, 3, 5, 6, 7, 8, 9, 12, 16 and 17 were repriced on 2026-10-01 for the parts added to make the design buildable (HBN-DDR-003): drip lip angle and frame brackets (1); rear posts, top frame, brackets, flanged duct collar and outlet hanger (3); reservoir stand, water post and band clips (5); electrolyzer feet (6); column bracket, pipe clips and separator drain valve (7); arrestor saddle and clip (8); tank cradle, M10 guard rods, nuts, tee nuts and top plate (9); fuel cell bridge (12); water lines and the vent line (16); T-nuts, self-tapping screws and sealant (17). Together they add USD 114.
- The H2Guard detector, fan and interlock (line 15) is costed in the H2Guard project and is **not** included in the total. The bench must not run without it.
- Line 10's vent valve is a needle valve set so that venting 300 to 20 kPa gauge takes 3 min or more (HBN-CAL-001 section 7). Its relief valve is set to 325 kPa gauge, and it carries a pressure switch that opens at 310 kPa gauge; the switch drives the relay in line 14, which breaks the electrolyzer supply (HBN-DDR-002). These added $20 to lines 10 and 14.
- Line 18 (plug-in 30 mA RCD) was added at TRL 3 because the safety sections require RCD protection and no line covered it.
- The existing lab table shown in the renders is not part of the BOM.
- Decided on 2026-10-02 (HBN-DEC-001) and carried into the BOM: line 9 names a certified aluminium cylinder (6061-T6 class, about 2 L, stamped 1 MPa or more, threaded neck; stainless only at about 1.0 kg or less), checked against the 112 mm cradle pocket (base 106 to 111 mm) with the neck thread still to match once a supplier is chosen; line 19, a catalytic deoxidizer, USD 60 (estimate, no quote); line 1, a 10 mm deck, USD 3 less. The bench power supply stays in the kit but stands beside the bench. Line 11 keeps its 12 V solenoid: the 24 V normally closed solenoid proposed to H2Guard is not priced until H2Guard agrees.

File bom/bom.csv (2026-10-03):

item | qty | spec | supplier | unit_cost_usd | make_buy | notes
1 Bench deck and extrusion frame | 1 | 20 x 20 mm aluminium extrusion frame, 900 x 450 mm (two 900 mm rails, four 410 mm rails) joined by eight inside corner brackets; 10 mm HDPE deck 900 x 450 mm, notched round the four posts, screwed to the frame with drop-in T-nuts; drip lip of 10 x 10 x 1.5 mm aluminium angle on the front and end edges, sealed with silicone; sits on an existing lab table | Extrusion supplier and plastics stockist | 57.00 | make | Indicative price; lip angle, brackets and T-nuts added for construction (HBN-DDR-003); deck 12 to 10 mm decided 2026-10-02: HDPE sheet bought by weight, 4.57 kg to 3.80 kg at about USD 4 per kg, USD 3 less; no quote
2 Instrument back panel | 1 | 3 mm aluminium composite panel, 900 x 570 mm, printed schematic of the energy chain | Sign maker | 15.00 | make | Indicative price
3 Canopy hood, duct and posts | 1 | Four 20 x 20 mm extrusion posts 582 mm and a top frame of the same extrusion (two 860 mm, two 305 mm rails) with 14 inside corner brackets; 3 mm polycarbonate canopy 900 x 345 mm with a 106 mm hole; bought flanged 100 mm duct collar; outlet hanger of 20 x 20 x 2 mm aluminium angle for the relief and vent lines | Plastics stockist | 65.00 | make | Indicative price; rear posts, top frame, brackets, collar and hanger added for construction (HBN-DDR-003); hydrogen rises into the hood where item 15 senses and extracts it
4 Bench DC power supply | 1 | Linear or switch-mode lab supply, 0 to 30 V, 0 to 10 A, constant-current mode, current limit set by the teacher | Electronics distributor | 65.00 | buy | Indicative price; part of the kit and counted in the value-engineering target (HBN-DDR-002); a school may use its own; ships in the kit and stands on the lab table beside the bench, not on the deck (HBN-DDR-003 A1, 2026-10-02)
5 DI water reservoir and deionizer | 1 | 500 mL HDPE reservoir with a vented lid and a side outlet, on a folded 2 mm aluminium stand 60 mm tall; mixed-bed resin cartridge with color change, 50 mm diameter, 150 mm tall; inline conductivity check to 1 uS/cm or less; both held by stainless band clips to a 200 mm length of 20 x 20 mm extrusion | Aquarium or lab supplier | 30.00 | buy | Indicative price; stand, post and band clips added for construction (HBN-DDR-003)
6 PEM electrolyzer stack | 1 | 4-cell PEM stack, about 7.8 V and 9 A (about 70 W), about 250 mL/min H2 at 20 C, H2 side rated to 300 kPa gauge or more, titanium plates; on two 40 x 20 x 3 mm aluminium angle feet bolted to its end plates | Electrolyzer supplier | 155.00 | buy | Estimate for a generic 4-cell stack; H2 side pressure rating must be confirmed (R10: 357 kPa gauge during a relief lift, HBN-CAL-001); for scale, MSE Supplies lists a single-cell 300 mL/min stack (45 A, 2.3 V, 2.5 kg) at $1,396.95; feet added for construction (HBN-DDR-003)
7 Gas and water separator and drier | 1 | Separator column with a manual drain valve at its foot, 50 g silica gel drier with indicator, both rated 1 MPa or more, held by two pipe clips to a folded 3 mm aluminium column bracket | Lab supplier | 30.00 | buy | Indicative price; column bracket, clips and drain valve added for construction (HBN-DDR-003); water is drained by hand and poured back into the reservoir; the catalytic deoxidizer (line 19) sits between the separator and the drier
8 Check valve and flame arrestor | 1 | Stainless check valve, 7 kPa cracking; inline sintered flame arrestor rated for hydrogen; HDPE saddle block and band clip | Gas equipment supplier | 28.00 | buy | Indicative price; saddle and clip added for construction (HBN-DDR-003)
9 Hydrogen buffer tank with guard | 1 | 2 L certified aluminium cylinder (6061-T6 class), stamped for 1 MPa working pressure or more, flat base 106 to 111 mm in diameter, threaded neck taking the manifold adapter, standing in a pocketed 20 mm HDPE cradle, inside a guard of four M10 stainless threaded rods with 16 nuts and a 4 mm aluminium top plate | Gas equipment supplier | 70.00 | buy | Estimate; plastic vessels excluded (permeation and burst risk); guard materials made explicit (HBN-DDR-003); aluminium cylinder decided 2026-10-02 (stainless only at about 1.0 kg or less). Fit windows from the model: base 106 to 111 mm diameter for the 112 mm cradle pocket (10 mm deep); neck thread to be matched to the manifold adapter once the supplier is chosen (no catalogue part confirmed on paper); price unchanged, not quoted
10 Tank manifold | 1 | 0 to 600 kPa absolute pressure transducer (0.25 % FS), 10 kOhm thermistor bonded to the shell, relief valve set to 325 kPa gauge, 0 to 600 kPa gauge, manual vent needle valve set so venting 300 to 20 kPa gauge takes 3 min or more, adjustable normally closed pressure switch set to open at 310 kPa gauge (high-pressure supply cut) | Gas equipment and electronics distributors | 60.00 | buy | Indicative price; relief and vent outlets piped to the hood; vent rate from HBN-CAL-001 section 7; relief 325 kPa gauge and 310 kPa gauge cut decided by Amish (HBN-DDR-002)
11 Regulator and solenoid valve | 1 | Low-pressure regulator 0 to 100 kPa out (set near 50 kPa for the fuel cell), 12 V normally closed solenoid valve on the tank outlet | Gas equipment supplier | 40.00 | buy | Indicative price; solenoid is closed by item 15 on alarm
12 PEM fuel cell | 1 | Open-cathode air-cooled PEM stack, 12 W class, 13 cells, 7.8 V at 1.5 A, H2 supply 45 to 55 kPa gauge, 0.18 L/min at full output, purity 99.995 % or better, 75 x 47 x 70 mm, about 275 g with fan and casing, integral purge valve; on a folded 2 mm aluminium bridge 40 mm tall | Fuel cell supplier | 253.00 | buy | Estimate for a generic stack; the branded Horizon H-12 lists at $576 (Fuel Cell Store, checked 2026-09-25); purity requirement to be met or waived by the supplier (R9); bridge added for construction (HBN-DDR-003)
13 Electronic load and lamp | 1 | Adjustable constant-current load 0 to 3 A with a 5 W LED lamp for a visible demonstration | Electronics distributor | 15.00 | buy | Indicative price
14 Meters logger and display | 1 | ESP32 board, three INA226 power monitors with shunts, ADC for pressure and temperature, 3.5 in display, CSV logging at 1 Hz; 12 V relay rated 10 A DC or more, driven by the line 10 pressure switch, breaking the electrolyzer supply line | Electronics distributor | 35.00 | buy | Indicative price; the cut relay works without the logger firmware
15 H2Guard sensor controller and fan | 1 | H2Guard project: hydrogen sensor at the hood high point, spark-free extraction fan, relay interlock to item 4 output and item 11 solenoid | H2Guard project | 0.00 | make | NOT INCLUDED in the H2Bench total; costed in the H2Guard BOM (H2Guard budget about $180)
16 Tubing fittings vent lines and wiring | 1 | PTFE or polyamide tubing 6 mm for the gas lines, the relief and vent lines to the outlet hanger and the three water lines (reservoir to cartridge, cartridge to stack, stack oxygen side back to the reservoir); compression fittings rated for hydrogen; fuses, 1.5 mm2 wire | Gas and electronics distributors | 38.00 | buy | Indicative price; water lines and vent line added for construction (HBN-DDR-003); the hood duct exhausts outdoors through H2Guard
17 Hardware and labels | 1 | Stainless fasteners (M4, M5, M6), drop-in T-nuts for 20-series slots, silicone sealant, cable ties, hazard and flow-direction labels | Hardware store | 20.00 | buy | Indicative price; T-nuts, sealant and more fasteners added for construction (HBN-DDR-003); not modelled
18 Plug-in RCD, 30 mA | 1 | Plug-in residual-current device (RCD or GFCI), 30 mA trip, for the bench power supply socket | Electrical wholesaler or hardware store | 20.00 | buy | Indicative price; optional where the bench socket is already RCD protected; not modelled
19 Catalytic deoxidizer | 1 | Palladium-catalyst hydrogen deoxidizer cartridge about 32 mm diameter x 120 mm, two 6 mm compression ports on top rated 1 MPa or more, with one band clip to the column bracket plate; stands on the bracket foot between the separator and the drier | Gas equipment or lab supplier | 60.00 | buy | Estimate, no quote: a small catalytic cartridge with fittings and clip; decided 2026-10-02 (HBN-DEC-001, item 4), removable only on supplier evidence of oxygen within 99.995 % purity at the bench's lowest operating current; assumed 99 % oxygen conversion, to confirm on the supplier's data; warms slightly while it reacts oxygen (HBN-CAL-001 section 8)

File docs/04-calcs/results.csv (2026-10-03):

id | value | target | status
R1 | Worst stage 1.8 % (hydrogen per fill 1.5 %, power 1 %) | Each within 5 % relative | Met
R2 | 17.7 min fill + 29.0 min discharge = 46.7 min | 60 min or less | Met
R3 | 70.2 W (79 W with aged cells) | 100 W or less | Met
R4 | 10.8 W net (11.7 W gross); 9.8 W if cells fall to 0.55 V | 10 to 50 W | Met
R5 | 8.5 L at 300 kPa g; 9.0 L at relief set; 9.9 L at full relief lift and 15 C | 10 L or less | Met
R6 | 300 kPa g working, relief 325 kPa g; hoop stress 18 MPa at 1 MPa | 300 / 350 kPa g or less; vessel 1 MPa or more | Met
R7 | 0.030 % vol (0.8 % LFL); 0.033 % worst case | Below 25 % LFL in 30 m3 | Met
R8 | 1.1 s from trip to valve closed, from H2Guard TRL 2 figures; H2Guard valve is 24 V, H2Bench solenoid 12 V | Trip cuts supply and closes solenoid within 2 s; fan runs | At risk
R9 | Water removed by the drier; deoxidizer fitted between separator and drier (decided 2026-10-02); residual oxygen 10 to 200 ppm at an assumed 99 % conversion and 0.1 to 2 % crossover, against 50 ppm for all impurities; no supplier data | 99.995 % or better (fuel cell listing) | At risk
R10 | Stack H2 side must hold 307 kPa in filling, 317 kPa at the supply cut and 332 kPa at relief set; no rating in hand | 332 kPa or more over the O2 side | At risk
R11 | Mixed-bed resin with conductivity check to 1 uS/cm; water use 3.4 g per fill | 1 uS/cm or less at the stack inlet | Met
R12 | 2804 rows per cycle, about 224 kB | V, I, P, p, T at 1 Hz to CSV | Met
R13 | 900 x 450 mm, 753 mm tall; 24.4 kg for the bench as moved, with the supply beside it (27.4 kg with the 3.0 kg supply) | 1000 x 500 mm, 800 mm, 25 kg or less (bench as moved, supply beside it) | Met
R14 | $1056 full; $991 without supply; $971 minimum (H2Guard excluded) | $885 value-engineering target (budget_usd, supply included) | Over the value-engineering target by $171
R15 | Guard clearance 50 mm; relief and vent piped to the canopy in the model | Guard, piped relief, no tool-free fitting | Met
R16 | Vent 3.0 min at the needle valve setting; setup time needs a walk-through with hardware | Setup 15 min or less; safe in 5 min or less | Not verifiable at TRL 3

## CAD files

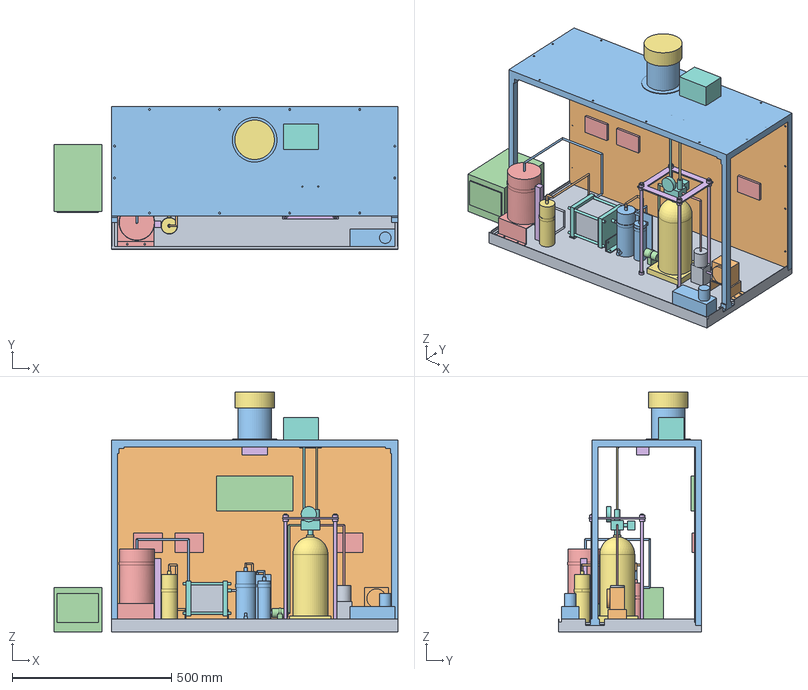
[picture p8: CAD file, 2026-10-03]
cad/step/h2bench-assembly.step
1080.0 x 450.0 x 753.0 mm

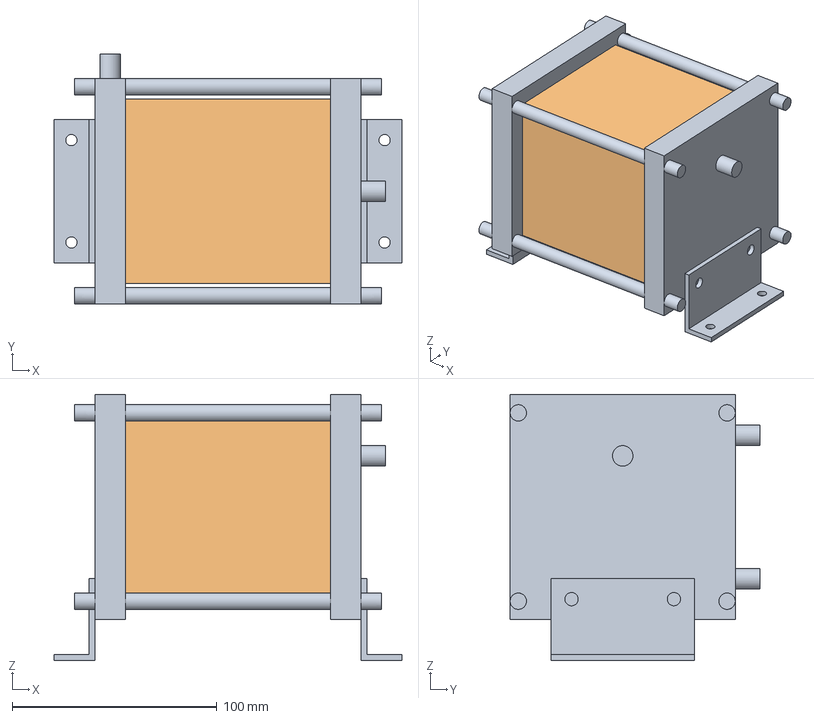
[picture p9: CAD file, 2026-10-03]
cad/step/h2bench-electrolyzer.step
170.0 x 122.0 x 130.0 mm

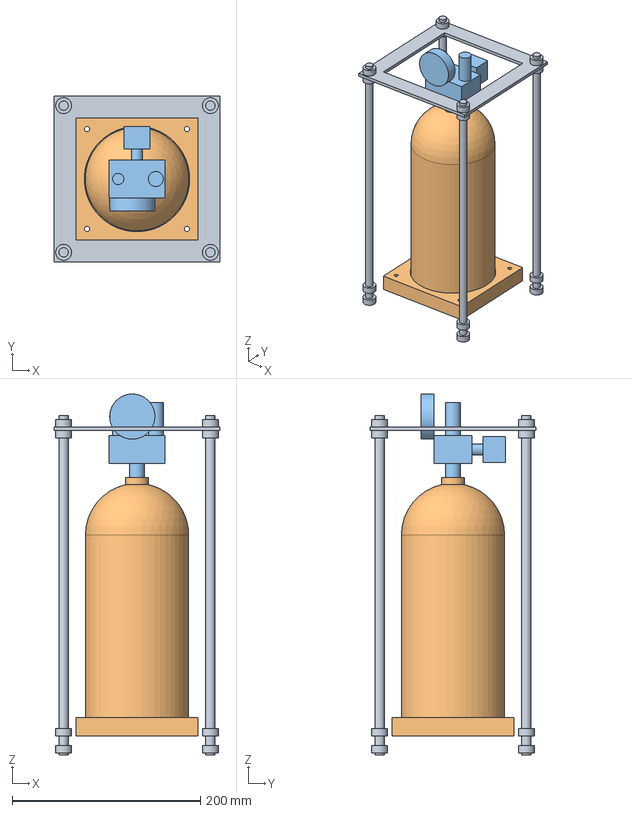
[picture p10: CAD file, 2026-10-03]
cad/step/h2bench-tank-module.step
176.0 x 176.0 x 383.8 mm

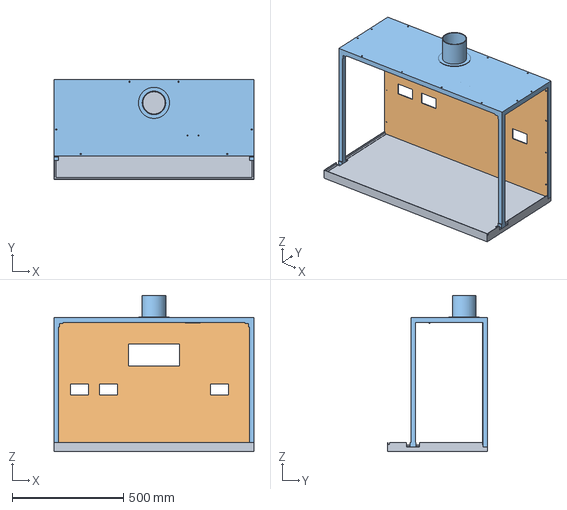
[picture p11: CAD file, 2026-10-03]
cad/step/h2bench-frame-and-hood.step
900.0 x 450.0 x 703.0 mm

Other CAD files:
cad/stl/h2bench-assembly.stl
cad/stl/h2bench-electrolyzer.stl
cad/stl/h2bench-frame-and-hood.stl
cad/stl/h2bench-tank-module.stl

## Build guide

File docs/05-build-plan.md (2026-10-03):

---
doc_id: HBN-BLD-001
title: H2Bench prototype build plan
project: H2Bench
doc_type: Build plan
version: "0.3"
status: Draft
date: '2026-10-02'
author: Amish Chadha
license: CERN-OHL-S-2.0
revisions:
  - version: "0.1"
    date: '2026-10-01'
    author: Amish Chadha
    change: First build plan; design made constructable (HBN-DDR-003)
  - version: "0.2"
    date: '2026-10-02'
    author: Amish Chadha
    change: "HBN-DDR-003 accepted (2026-10-02); separator drain rule"
  - version: "0.3"
    date: '2026-10-02'
    author: Amish Chadha
    change: "10 mm deck, supply beside the bench, catalytic deoxidizer between separator and drier, aluminium tank named, pictures redrawn (HBN-DEC-001, items 2, 4 and 6)"
---

# H2Bench prototype build plan

**Plan, not yet built.** How to build the first proof-of-concept prototype, component by component. Building and testing to it is TRL 4 work. Decisions still to be made are kept in the design decisions register ([docs/06-design-decisions.md](06-design-decisions.md)), not here.

## 1. What you are building

Figure 1. Every component, pulled apart and numbered in build order

*Figure 1. Every component pulled apart and numbered in build order.*

The prototype is one H2Bench: a 900 x 450 mm aluminium-framed deck that sits on an existing lab table, with a clear canopy hood 570 mm above it on four posts and a printed instrument panel across the back. The bench power supply stands on the lab table beside the left end of the bench. On the deck, from left to right in the order the energy flows, stand a water reservoir and deionizer, a small electrolyzer stack, a separator, a catalytic deoxidizer and a drier, a check valve and flame arrestor, a 2 L hydrogen tank in a rod guard with its manifold, a regulator, a fuel cell and a lamp load. The H2Guard detector, fan and controller sit at the high point of the hood. Figure 1 shows the 27 components in the order you make or fit them. The frame, deck, lip, posts, top frame, panel, canopy and eight small mounts are made in a workshop; the rest are bought and fitted. The work is sawing and drilling aluminium extrusion, folding thin aluminium sheet, cutting HDPE and polycarbonate sheet, fitting compression fittings to 6 mm tubing and wiring bought modules. The parts cost about USD 1,056 from the bill of materials.

> **Safety:** This bench makes, stores and uses hydrogen, which burns in air from about 4 to 74 % and ignites very easily, and holds it at up to 300 kPa gauge. Nothing in sections 3 and 4 uses hydrogen: the build is dry until the safety stops of section 6. Never connect the electrolyzer, pressurize the tank or open the hydrogen line until those stops say so, and never run the bench without H2Guard active. The bench supply is mains powered: use it only on an earthed socket with a 30 mA RCD. Cut aluminium and polycarbonate edges are sharp; deburr everything.

## 2. What changed to make it buildable

The concept showed what the bench does; some of its parts could not be made or fixed as drawn. Each change below keeps what the bench does, and all of them are recorded in decision record HBN-DDR-003, made under Amish's 2026-09-30 instruction to make the design physically buildable and accepted by him on 2026-10-02.

*Table 1. Changes from the concept.*

| Component | The concept had | The buildable design has | Why |
| --- | --- | --- | --- |
| Frame | One fused shape, bars overlapping at every corner | Six cut lengths of slotted extrusion joined by inside corner brackets (Figure 3) | Standard parts, no welding |
| Drip lip | Moulded into the HDPE deck | Aluminium angle screwed on a silicone bead; the panel closes the back (Figure 8) | HDPE cannot be glued or moulded in a workshop |
| Posts and canopy | Two front posts standing on the lip; the canopy held only at the front; the panel held by nothing | Four posts on the frame, a top frame, the canopy screwed to it, the panel screwed to the rear posts (Figures 6, 8, 10) | A closed frame carries the canopy and fan |
| Duct collar | Fused into the canopy | Bought flanged spigot through a 106 mm hole (Figure 13) | Bought part |
| Relief and vent lines | Relief line pressed against the canopy, unsupported; no vent line | Both lines clipped to a hanger, ending 7 mm below the canopy (Figure 12) | The gas must get out into the hood |
| Water side | Not drawn | Reservoir on a 60 mm stand, three water lines to and from the stack (Figures 14, 25) | The stack is fed by gravity |
| Electrolyzer | Tie rods through its cell plates; feet that could not be screwed down | Rods clear of the plates; two angle feet bolted to the end plates (Figure 16) | Every screw can be reached |
| Separator, deoxidizer and drier | Loose, 3 mm apart in line with no room for fittings; no deoxidizer | On a column bracket with pipe clips; the deoxidizer stands on the bracket foot between them; gas loops over from the separator top, through the deoxidizer, to the drier top (Figure 18) | Room for every fitting; removes the oxygen that crosses the stack membrane |
| Deck and power supply | 12 mm deck; supply on the deck at the left | 10 mm deck; supply stands on the lab table beside the left end of the bench | Lighter bench; the deck stays clear of the mains lead |
| Arrestor | 150 mm up on a post block | 60 mm up in an HDPE saddle straight off the drier outlet (Figure 20) | Short, supported run clear of the tank |
| Tank guard | Rods standing loose; a top ring that would need welding | Threaded rods in tee nuts, a bolted top plate, the tank in a pocketed cradle (Figure 22) | No welding; the tank cannot tip or lift |
| Fuel cell stand | A solid block in the fan's air path | A folded bridge, open front and back (Figure 24) | Air flows through the stack |

## 3. Making the components

Make and check each component before the assembly step that needs it. Sizes are in millimetres. "Left" and "right" are as seen standing at the front of the bench (the student side); "front" is the student side and "back" the instrument panel. Heights are above the lab table unless a step says otherwise; the deck top is 30 mm above the table. Workshop tolerance is 0.5 mm unless a step says otherwise; drawings do not carry tolerances before TRL 4.

All extrusion, brackets and T-nuts are one 20-series system (20 x 20 mm profile, 6 mm slot). Mounts are fixed to the deck with 5 mm stainless self-tapping screws in 4 mm pilot holes, 10 mm deep, marked through the mount's own holes with the mount in place (Table 2).

*Table 2. Where each mount goes on the deck, measured from the left end and from the front edge of the deck.*

| Mount | From the left end | From the front edge |
| --- | --- | --- |
| Reservoir stand (top) | 20 to 134 | 25 to 145 |
| Water post (centre) | 146 | 80 |
| Electrolyzer end plates | 235 to 365, feet 215 to 385 | centred 185 |
| Separator and drier (centres) | 422 and 480 | 185 |
| Deoxidizer (centre, on the bracket foot) | 451 | 244 |
| Column bracket (face) | 402 to 502 | 220 |
| Arrestor saddle (centre) | 530 | 185 |
| Tank cradle and guard (centre) | 625 | 185 |
| Regulator (centre) | 730 | 185 |
| Fuel cell bridge | 790 to 875 | centred 185 |
| Load and lamp | 750 to 890 | 10 to 65 |

### 3.1 Frame

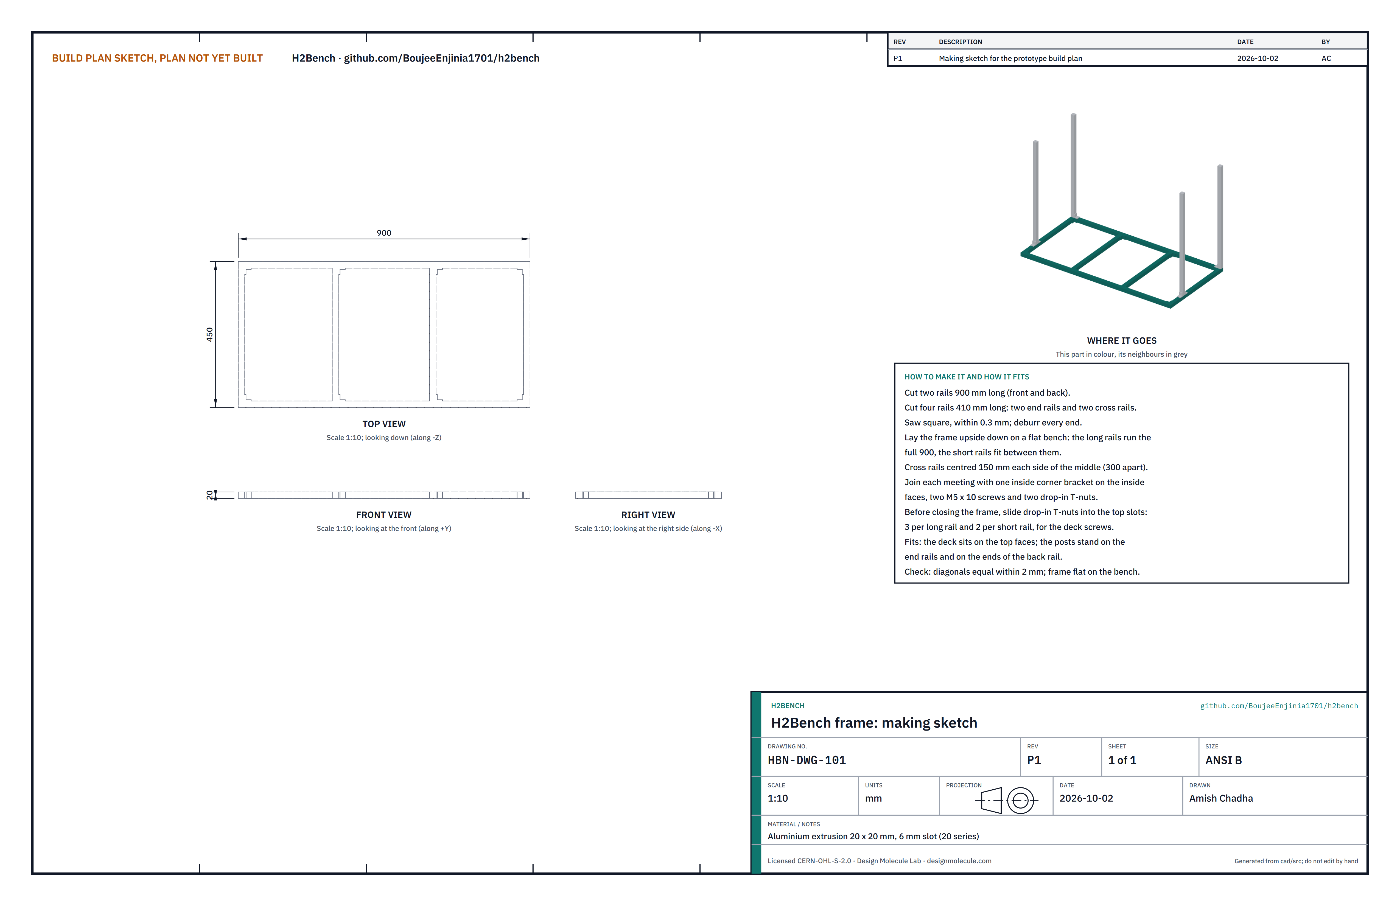
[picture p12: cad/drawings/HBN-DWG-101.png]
Figure 2. Making sketch of the frame


*Figure 2. Frame making sketch (HBN-DWG-101).*

**What it is and what it is made from.** The rectangle the deck sits on and the posts stand on. 20 x 20 mm slotted aluminium extrusion, 3.44 m in all.

**How to make it.**

1. Cut two rails 900 long (front and back) and four rails 410 long (two end rails and two cross rails). Saw square within 0.3 mm and deburr every end.
2. Lay the rails upside down on a flat bench: the long rails run the full 900; the short rails fit between them, the end rails flush with the ends and the cross rails centred 150 each side of the middle.
3. Before closing the frame, slide drop-in T-nuts into the top slots: three in each long rail and two in each short rail, for the deck screws.
4. Join each meeting with one inside corner bracket on the inside faces, two M5 x 10 screws into T-nuts.

**How it fits the parts next to it.**

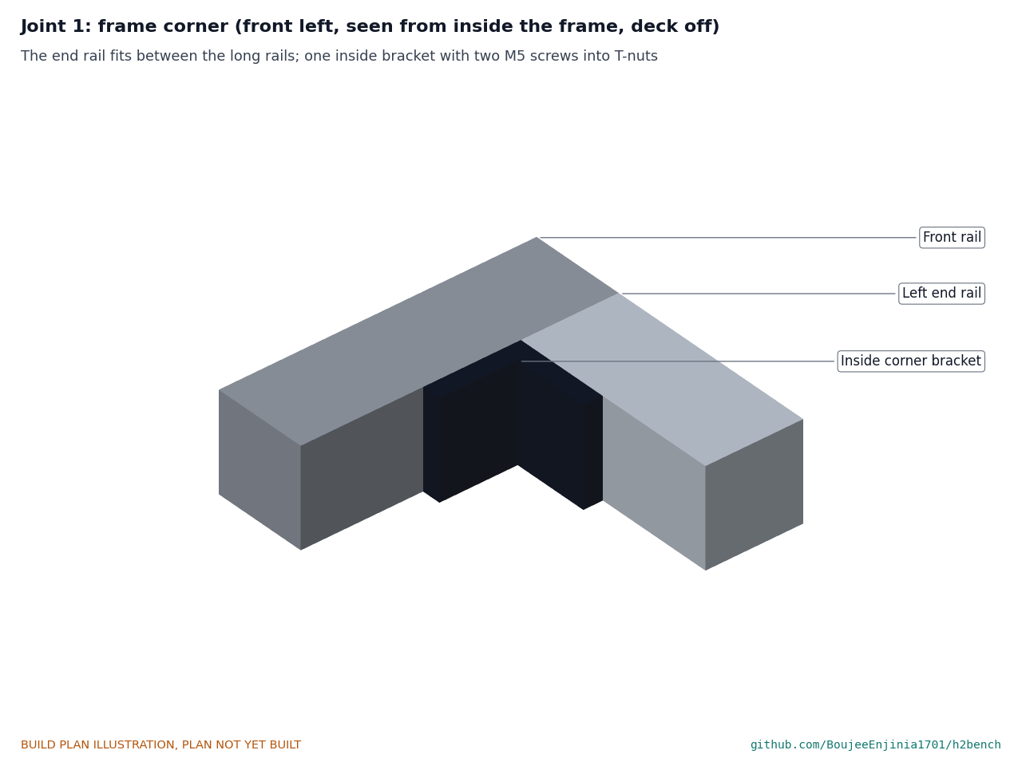
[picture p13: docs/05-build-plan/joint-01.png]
Figure 3. Joint 1: frame corner


*Figure 3. The end rail butts between the long rails; one inside bracket holds each meeting.*

The deck lies on the top faces. The front posts stand on the end rails and the rear posts on the ends of the back rail (Figure 6).

**Check before moving on.** The diagonals are equal within 2 mm and the frame lies flat on the bench without rocking.

### 3.2 Deck, water post and drip lip

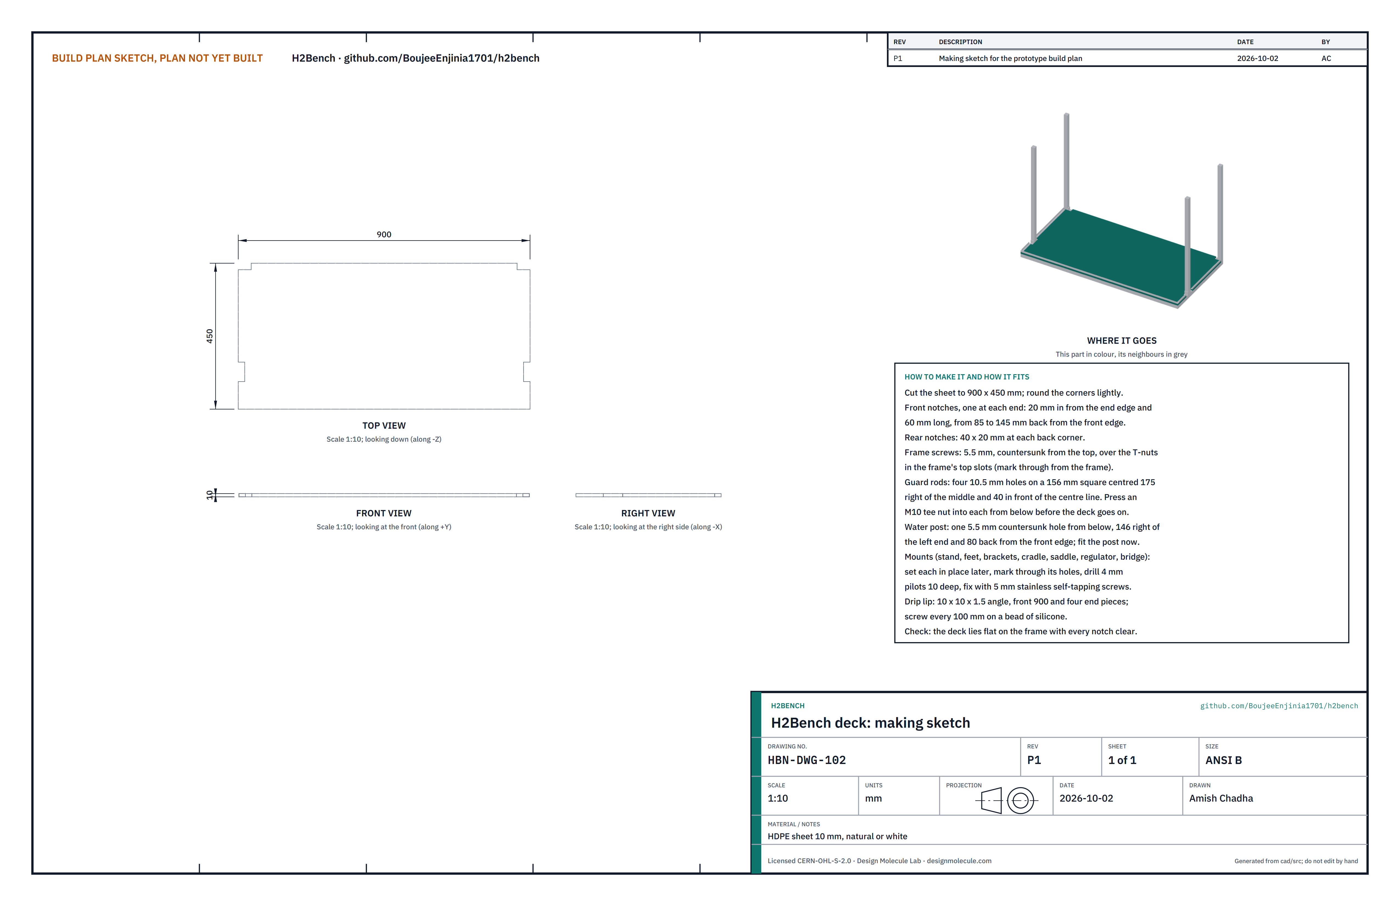
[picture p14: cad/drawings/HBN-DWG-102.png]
Figure 4. Making sketch of the deck


*Figure 4. Deck making sketch (HBN-DWG-102), with the drip lip and the holes that must be made before the deck goes on.*

**What it is and what it is made from.** The wet tray everything stands on. HDPE sheet 10 mm, 900 x 450; aluminium angle 10 x 10 x 1.5 mm for the lip; a 200 mm length of the frame extrusion for the water post.

**How to make it.**

1. Cut the sheet to 900 x 450 and round the corners lightly.
2. Cut the front notches, one at each end: 20 in from the end edge, from 85 to 145 back from the front edge. Cut the rear notches 40 x 20 at each back corner.
3. Set the deck on the frame, mark through from the T-nuts, and drill 5.5 mm, countersunk from the top, for the frame screws.
4. Drill four 10.5 mm holes for the guard rods on a 156 mm square centred 625 from the left end and 185 from the front edge. Press an M10 tee nut into each from below.
5. Drill one 5.5 mm hole, countersunk from below, 146 from the left end and 80 from the front edge, and screw the water post (Figure 5) to the deck through it, into its tapped end.
6. Cut the lip angle: one piece 900 for the front, and two pieces 75 and two pieces 282 for the ends (they stop at the post notches and at the panel).

**How it fits the parts next to it.** The deck lies on the frame on countersunk M5 screws into the T-nuts. The lip angles go on in step 2 with one leg flat on the deck at its edge and the other standing 10 up, screwed every 100 mm on a bead of silicone; the panel closes the back edge (Figure 8).

**Check before moving on.** The deck lies flat on the frame with every notch clear of the brackets; the tee nuts are flush underneath; the water post stands upright.

### 3.3 Posts

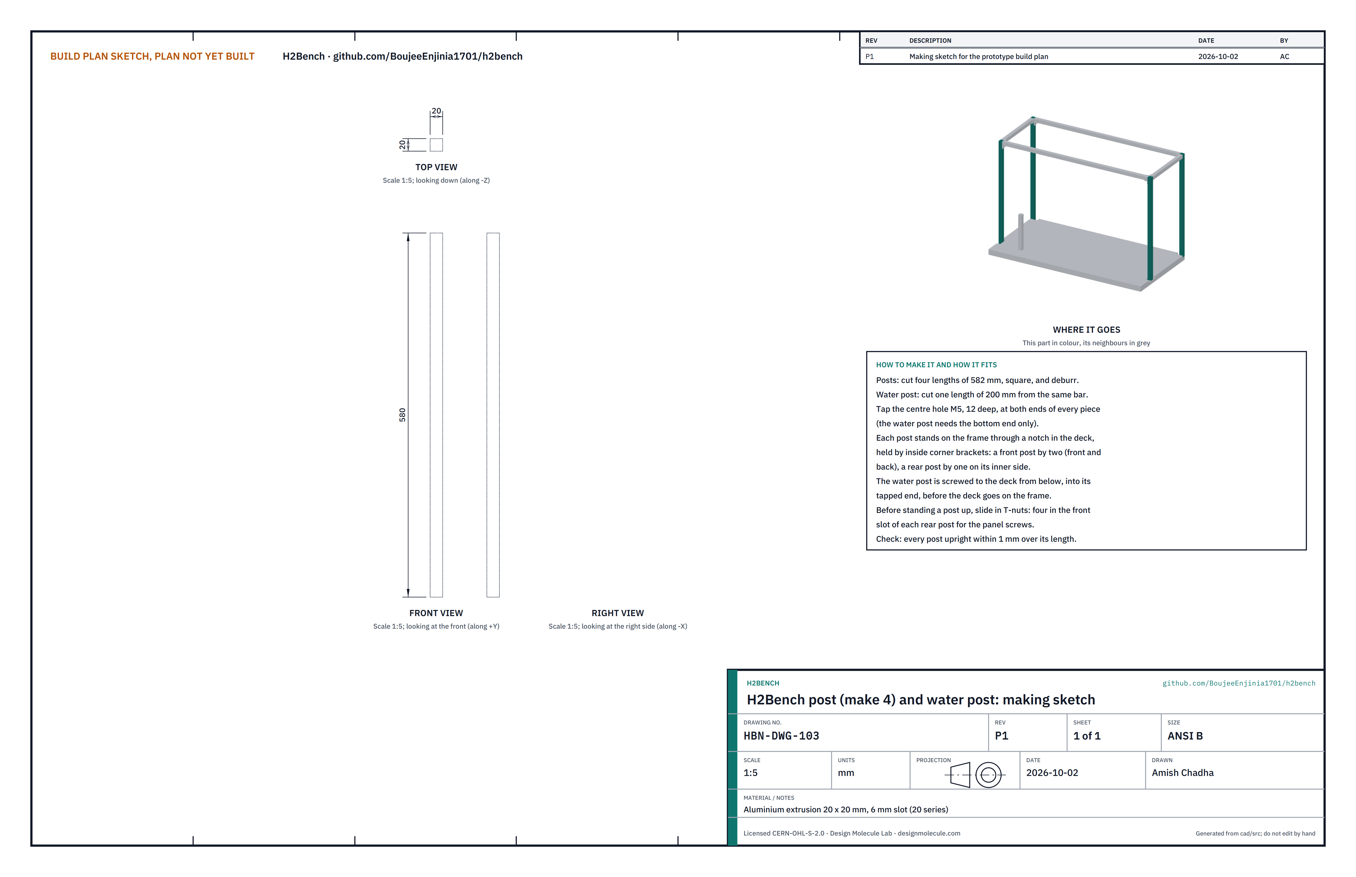
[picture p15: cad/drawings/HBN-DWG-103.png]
Figure 5. Making sketch of the post and the water post


*Figure 5. Post and water post making sketch (HBN-DWG-103).*

**What it is and what it is made from.** Four uprights that carry the top frame, canopy and panel. 20 x 20 mm extrusion.

**How to make it.**

1. Cut four lengths of 582, square, and deburr. (Cut the 200 mm water post from the same bar.)
2. Tap the centre hole M5, 12 deep, at both ends of every post; the water post needs its bottom end only.
3. Slide four T-nuts into the front slot of each rear post for the panel screws.

**How it fits the parts next to it.**

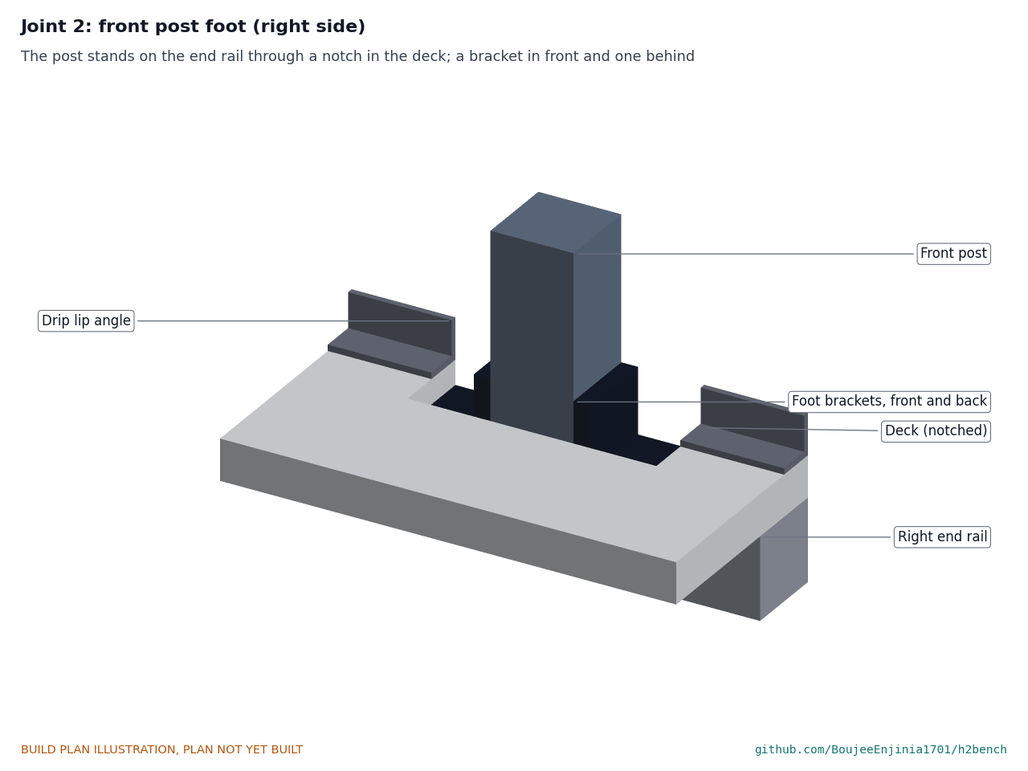
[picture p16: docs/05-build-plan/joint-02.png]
Figure 6. Joint 2: front post foot


*Figure 6. A front post stands on the end rail through a notch in the deck, held by an inside bracket in front and one behind. A rear post has one bracket, on its inner side (Figure 8).*

**Check before moving on.** Every post is upright within 1 mm over its length.

### 3.4 Instrument back panel

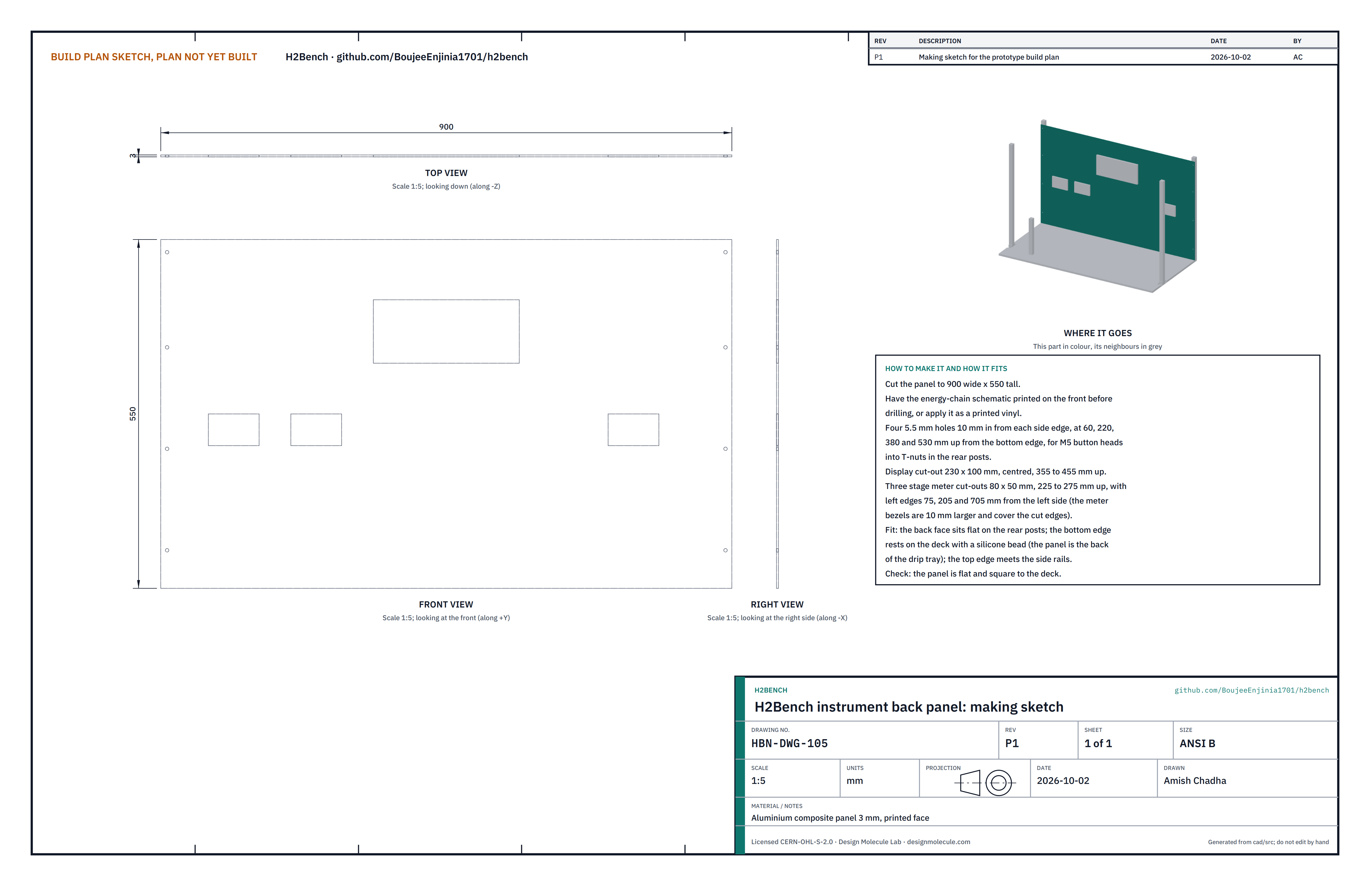
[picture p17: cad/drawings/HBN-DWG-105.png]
Figure 7. Making sketch of the instrument panel


*Figure 7. Instrument back panel making sketch (HBN-DWG-105).*

**What it is and what it is made from.** The back wall of the bench, printed with the energy-chain schematic, carrying the display and the three stage meters. Aluminium composite panel 3 mm.

**How to make it.**

1. Cut the panel 900 wide x 550 tall. Have the schematic printed on the front first, or apply it as printed vinyl.
2. Drill four 5.5 mm holes 10 in from each side edge, at 60, 220, 380 and 530 up from the bottom edge.
3. Cut the display opening 230 x 100, centred, 355 to 455 up from the bottom edge.
4. Cut three meter openings 80 x 50, 225 to 275 up, with their left edges 75, 205 and 705 from the left side. Check each opening against the meter you bought before cutting; the bezels cover the cut edges.

**How it fits the parts next to it.**

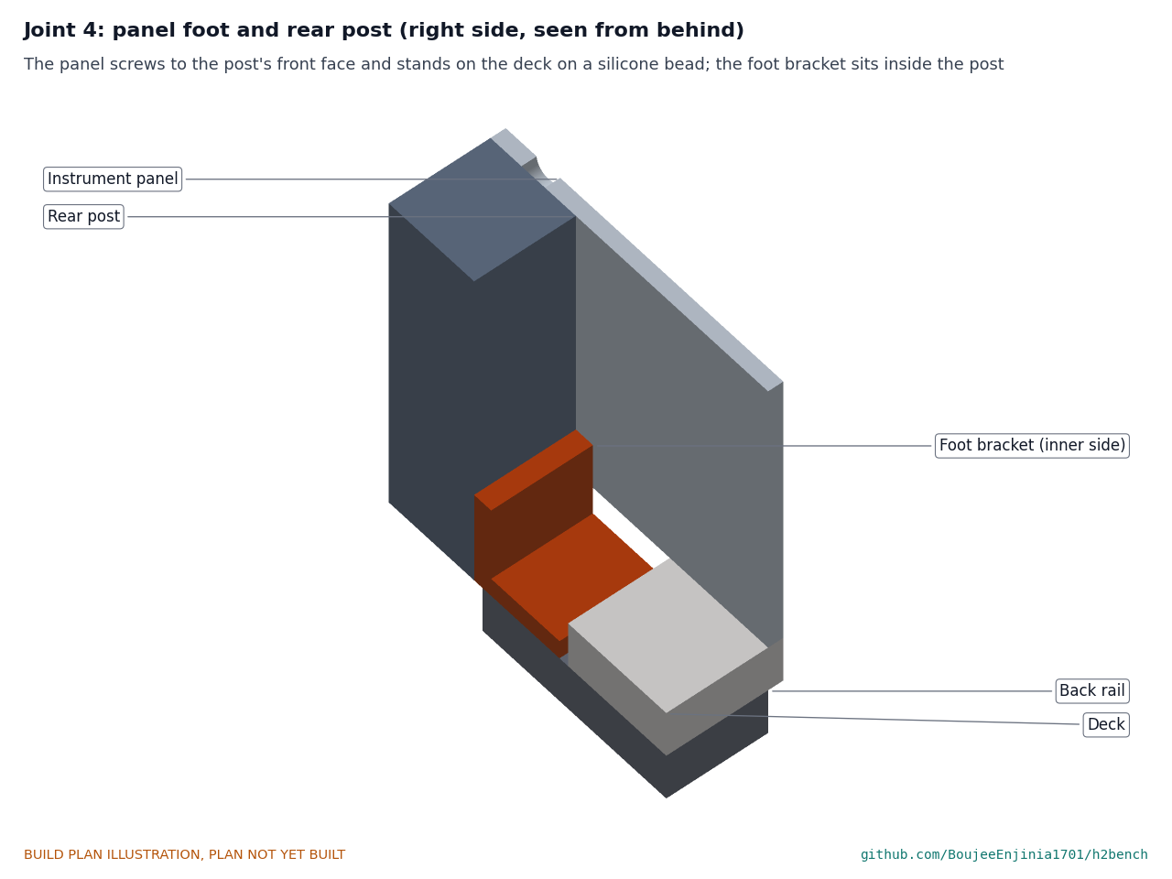
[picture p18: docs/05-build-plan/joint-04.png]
Figure 8. Joint 4: panel foot and rear post


*Figure 8. Seen from behind. The panel screws to the front face of the rear post and stands on the deck; the post's foot bracket sits on its inner side.*

The back face sits flat on the rear posts on M5 button-head screws into the T-nuts; the bottom edge stands on the deck on a bead of silicone, which closes the back of the drip tray; the top edge meets the underside of the side top rails.

**Check before moving on.** The panel is flat and square to the deck.

### 3.5 Top frame

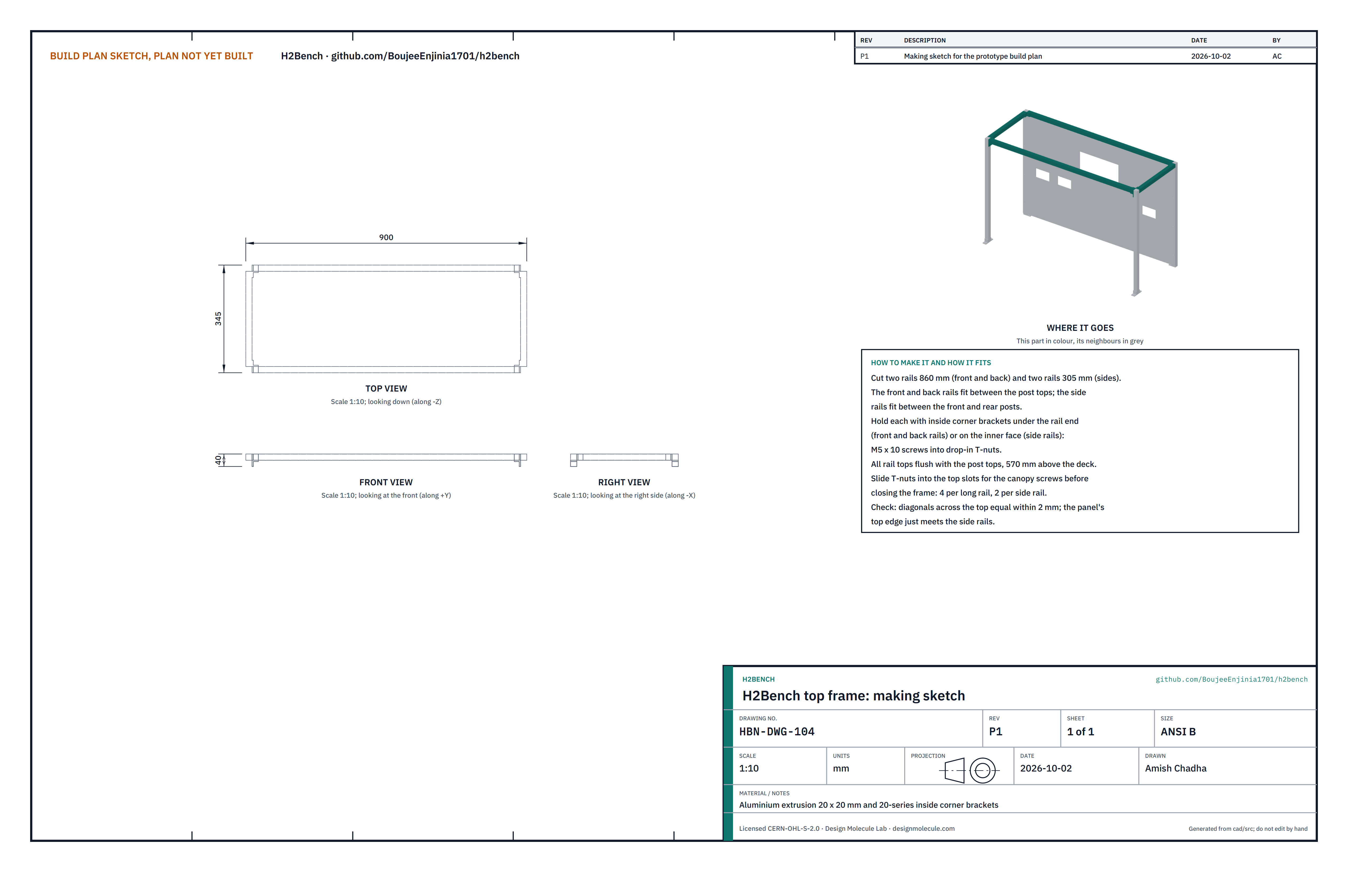
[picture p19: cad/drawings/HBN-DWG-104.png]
Figure 9. Making sketch of the top frame


*Figure 9. Top frame making sketch (HBN-DWG-104).*

**What it is and what it is made from.** The rectangle at the top of the posts that the canopy lies on. 20 x 20 mm extrusion and eight inside corner brackets.

**How to make it.**

1. Cut two rails 860 (front and back) and two rails 305 (sides).
2. Slide T-nuts into the top slots for the canopy screws: four in each long rail and two in each side rail.

**How it fits the parts next to it.**

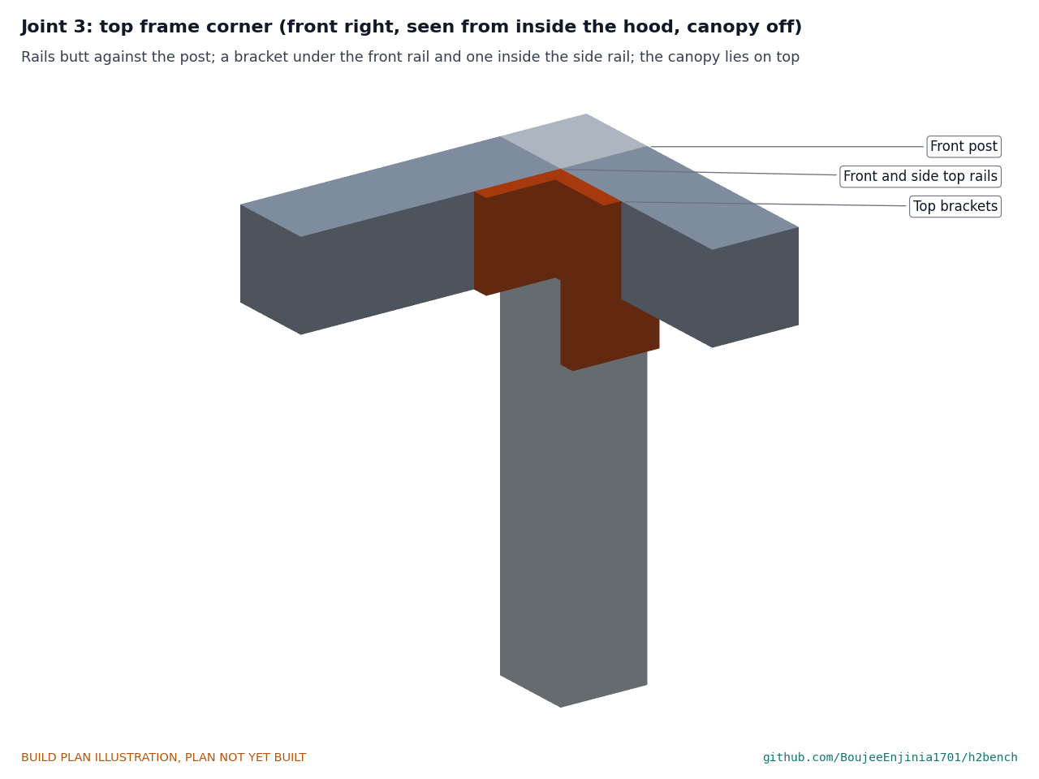
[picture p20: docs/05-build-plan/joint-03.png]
Figure 10. Joint 3: top frame corner


*Figure 10. Seen from inside the hood with the canopy off. The rails butt against the post; a bracket under each long rail and one inside each side rail; the canopy lies on top.*

All rail tops are flush with the post tops, 570 above the deck.

**Check before moving on.** The diagonals across the top are equal within 2 mm.

### 3.6 Canopy, duct collar and outlet hanger

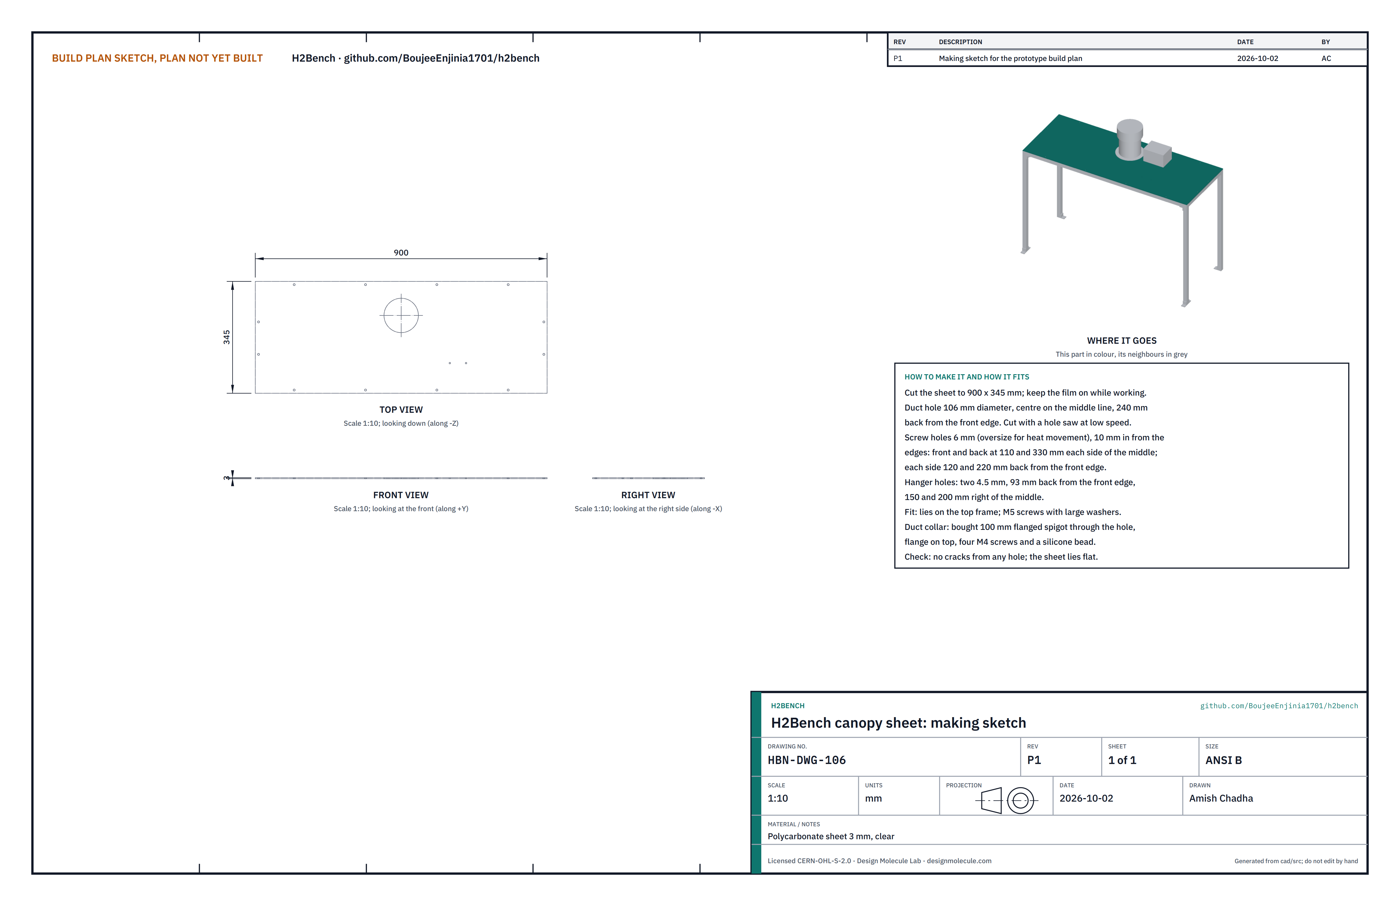
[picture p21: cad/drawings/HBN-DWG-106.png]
Figure 11. Making sketch of the canopy


*Figure 11. Canopy making sketch (HBN-DWG-106).*

**What it is and what it is made from.** The clear hood that gathers any hydrogen at one high point, the duct, for the H2Guard sensor and fan. Polycarbonate sheet 3 mm, a bought 100 mm flanged duct collar, and a 70 mm length of 20 x 20 x 2 mm aluminium angle for the outlet hanger.

**How to make it.**

1. Cut the sheet 900 x 345, keeping the film on while working.
2. Cut the duct hole 106 across, centred on the middle line, 240 back from the front edge, with a hole saw at low speed.
3. Drill 6 mm screw holes (oversize, so the sheet can move with heat) 10 in from the edges: front and back at 110 and 330 each side of the middle; each side 120 and 220 back from the front edge.
4. Drill two 4.5 mm hanger holes 93 back from the front edge, 150 and 200 right of the middle.
5. Make the outlet hanger (Figure 12): two 4.5 mm holes in the flat leg 10 from each end, two 6.5 mm clip holes in the hanging leg 15 and 55 from the left end, 10 below the canopy.

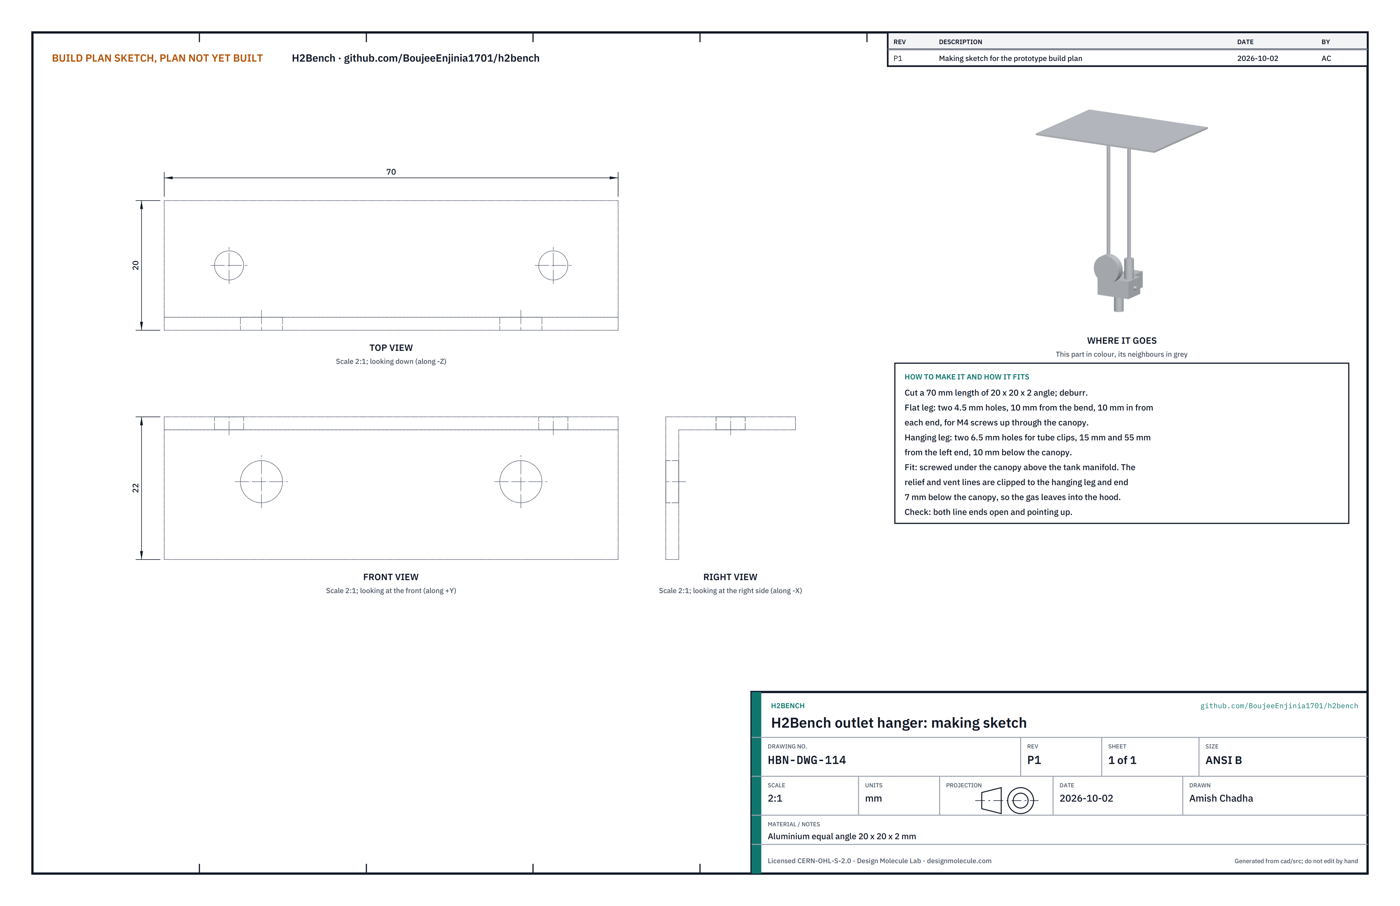
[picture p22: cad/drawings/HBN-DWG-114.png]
Figure 12. Making sketch of the outlet hanger


*Figure 12. Outlet hanger making sketch (HBN-DWG-114).*

**How it fits the parts next to it.**

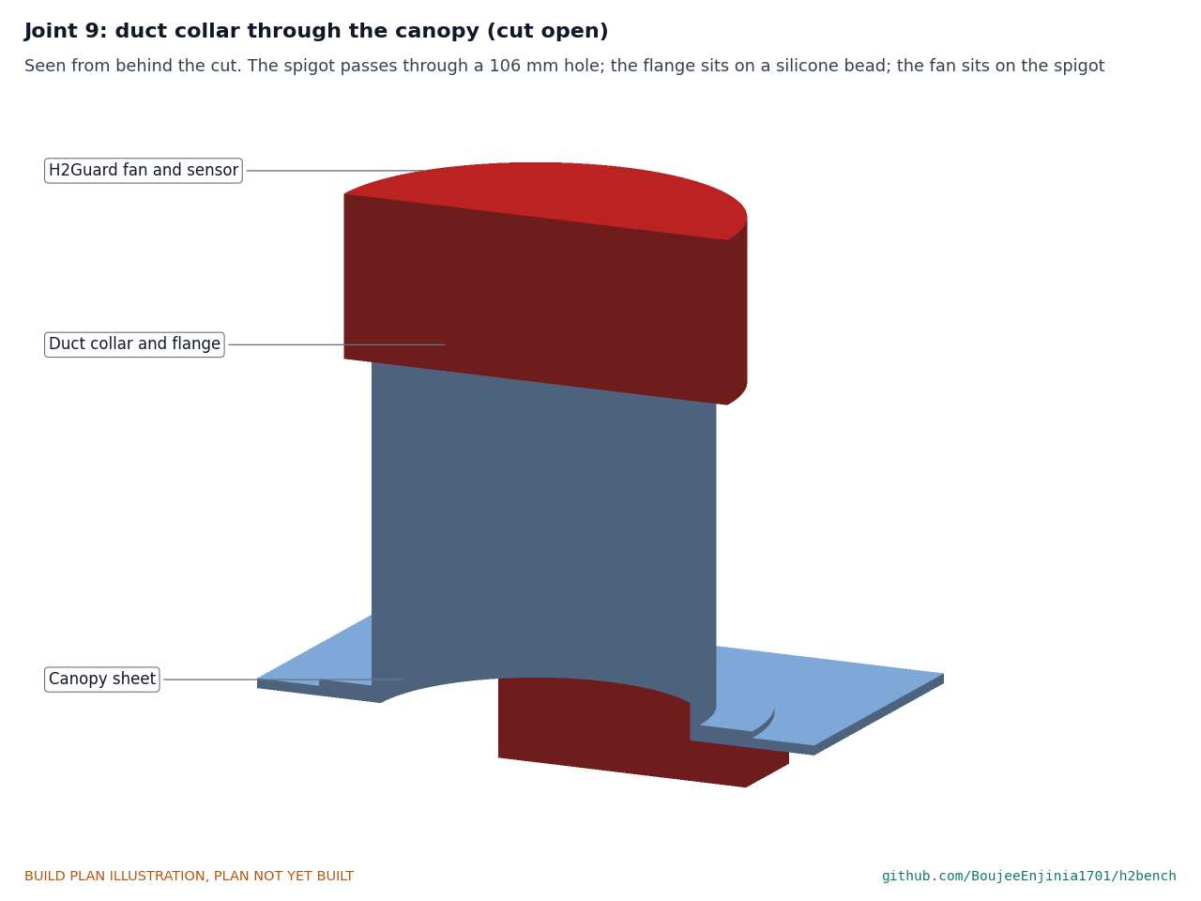
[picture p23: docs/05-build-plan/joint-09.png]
Figure 13. Joint 9: duct collar through the canopy


*Figure 13. Cut open. The spigot passes through the hole and its flange sits on the sheet on a silicone bead with four M4 screws; the H2Guard fan sits on the spigot.*

The sheet lies on the top frame on M5 screws with large washers. The hanger is screwed under the sheet above the tank manifold with two M4 screws, nuts on top.

**Check before moving on.** No cracks run from any hole; the sheet lies flat.

### 3.7 Reservoir stand

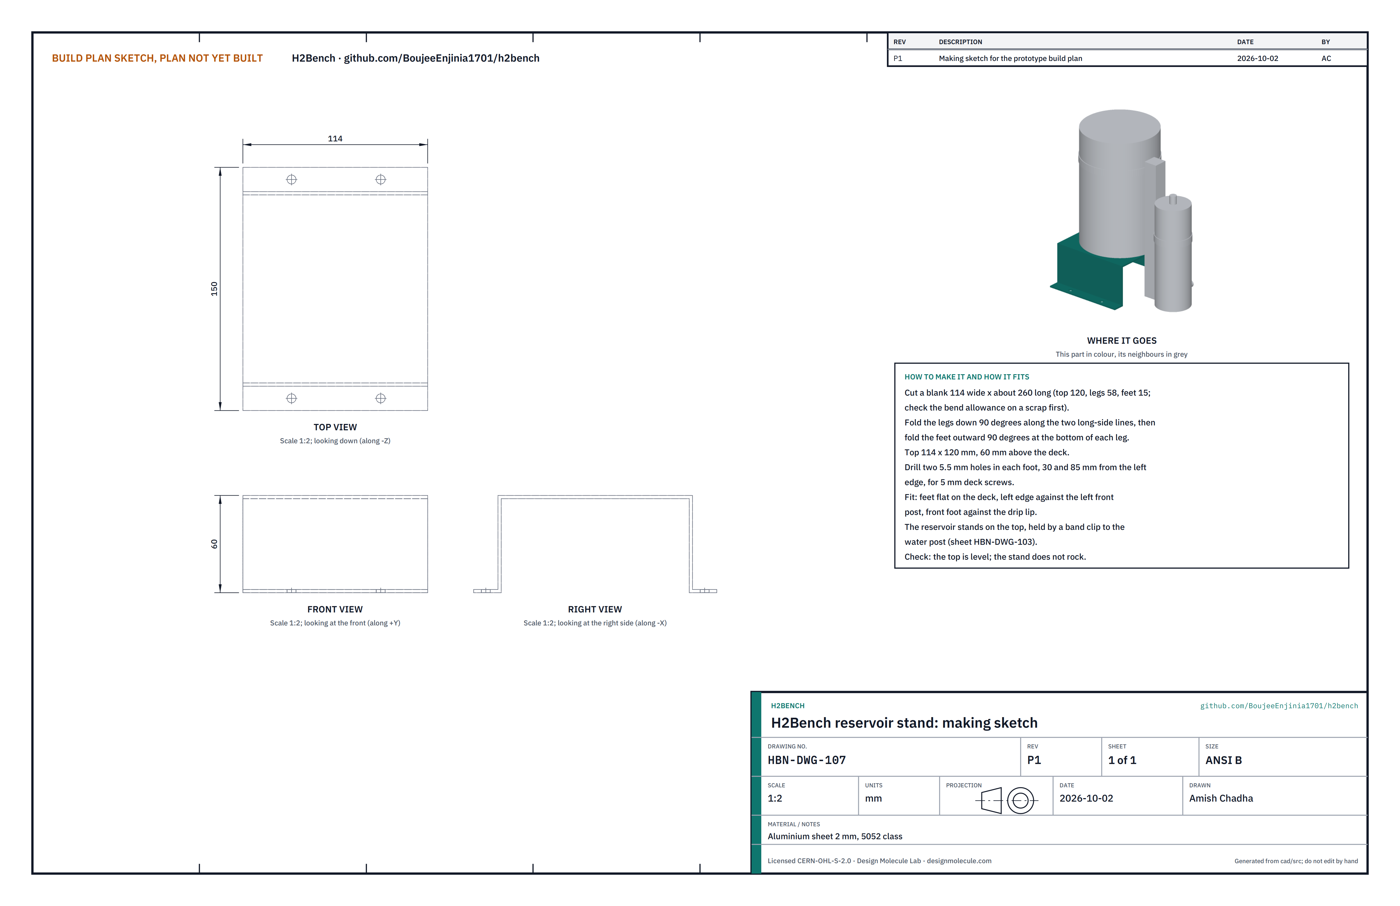
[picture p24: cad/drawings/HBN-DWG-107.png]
Figure 14. Making sketch of the reservoir stand


*Figure 14. Reservoir stand making sketch (HBN-DWG-107).*

**What it is and what it is made from.** A folded stand that lifts the water reservoir 60 mm, so its water stands above the electrolyzer's water inlet and feeds it by gravity. Aluminium sheet 2 mm.

**How to make it.**

1. Cut a blank 114 wide x about 260 long (top 120, legs 58, feet 15); check the bend allowance on a scrap first.
2. Fold the legs down 90 degrees along the two long-side lines, then the feet outward 90 degrees.
3. Drill two 5.5 mm holes in each foot, 30 and 85 from the left edge.

**How it fits the parts next to it.** The feet lie flat on the deck, the left edge against the left front post and the front foot against the drip lip. The reservoir stands on the top; a band clip holds it to the water post at mid height, and a second band clip holds the deionizer cartridge to the other side of the post.

**Check before moving on.** The top is level and the stand does not rock.

### 3.8 Electrolyzer feet

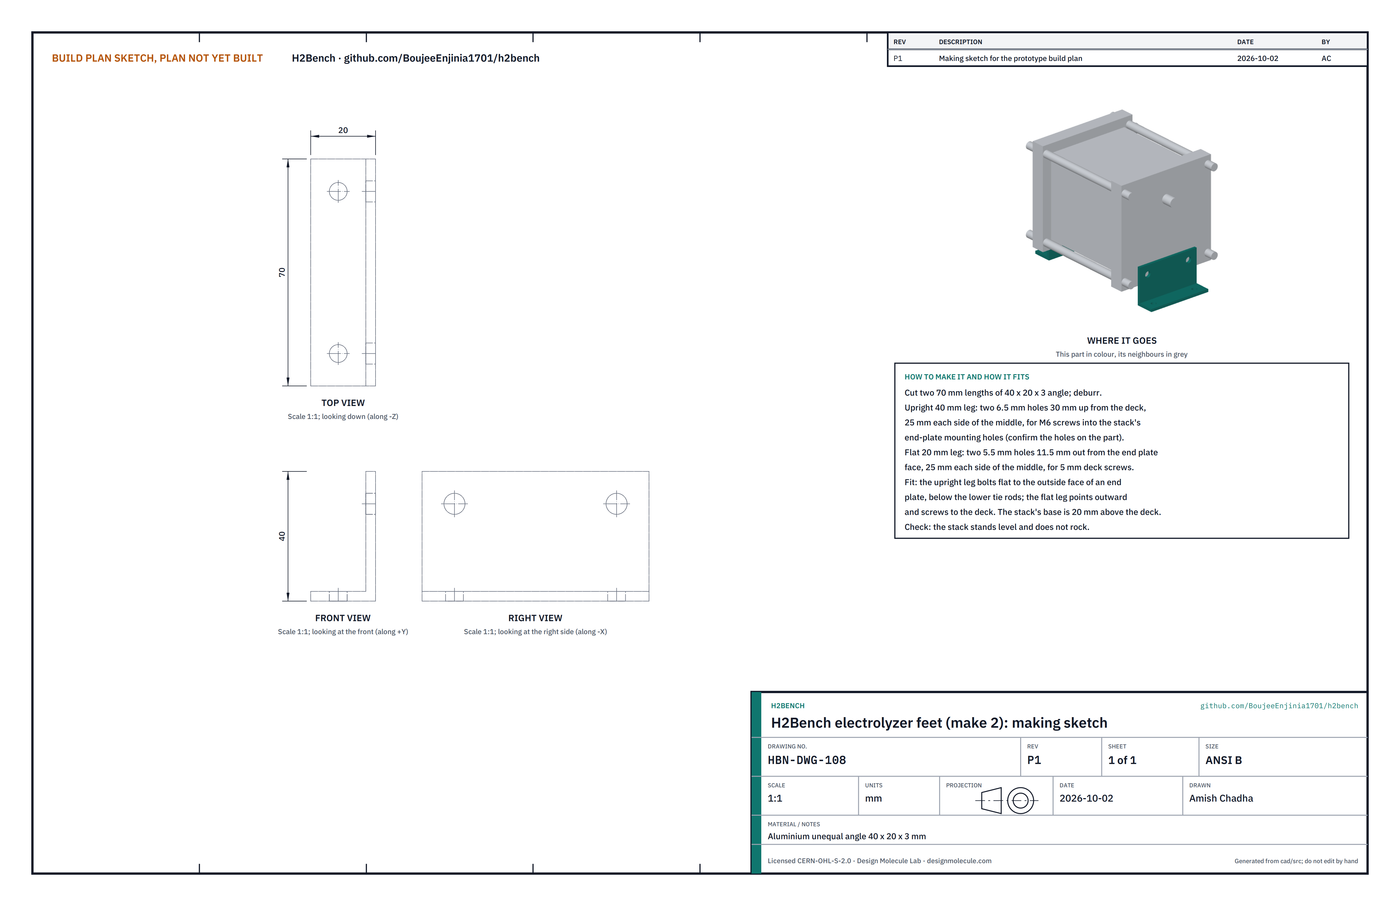
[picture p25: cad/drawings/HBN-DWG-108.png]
Figure 15. Making sketch of the electrolyzer feet


*Figure 15. Electrolyzer feet making sketch (HBN-DWG-108).*

**What it is and what it is made from.** Two feet that carry the bought electrolyzer by its end plates. Aluminium unequal angle 40 x 20 x 3 mm.

**How to make it.**

1. Cut two 70 lengths and deburr.
2. Upright 40 leg: two 6.5 mm holes 30 up from the deck, 25 each side of the middle, to suit the stack's end-plate mounting holes (check them on the stack before drilling).
3. Flat 20 leg: two 5.5 mm holes 11.5 out from the end-plate face, 25 each side of the middle.

**How it fits the parts next to it.**

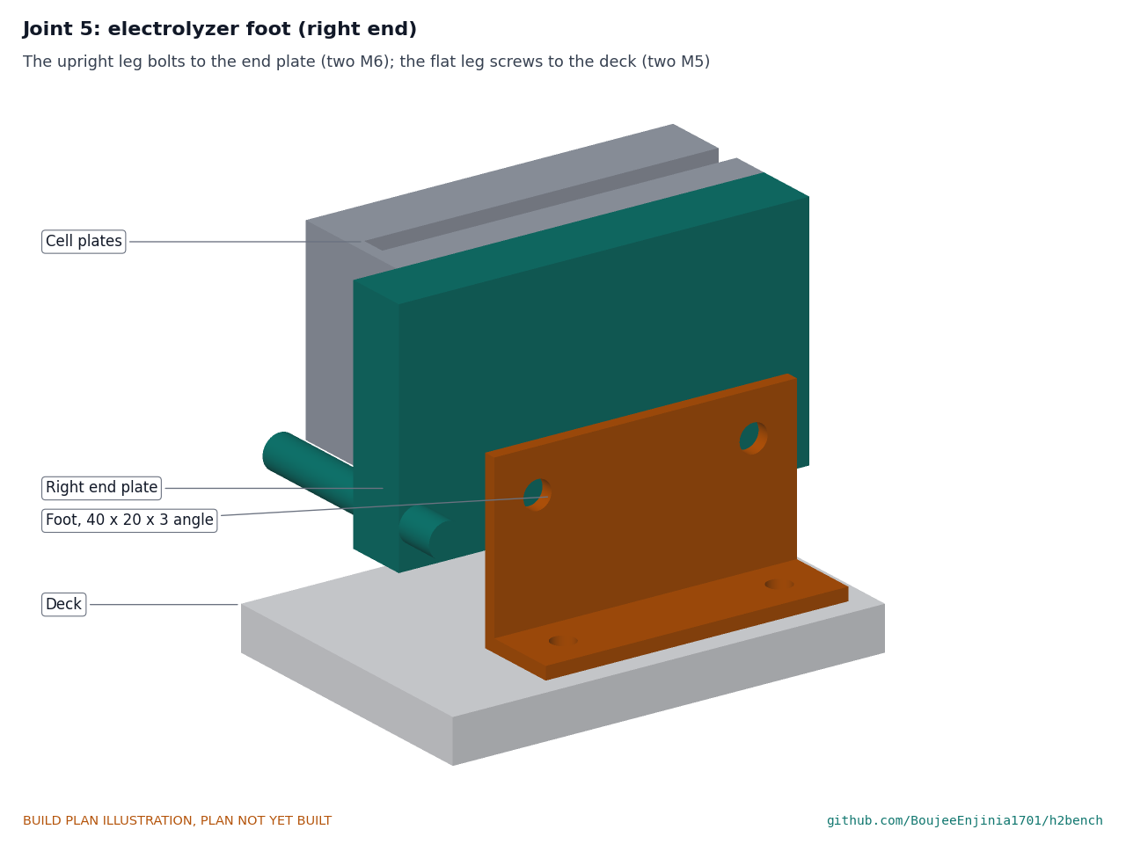
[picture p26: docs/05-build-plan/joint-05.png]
Figure 16. Joint 5: electrolyzer foot


*Figure 16. The upright leg bolts flat to the outside face of an end plate, below the lower tie rods; the flat leg points outward and screws to the deck.*

The stack's base sits 20 above the deck.

**Check before moving on.** With the feet on, the stack stands level and does not rock.

### 3.9 Column bracket

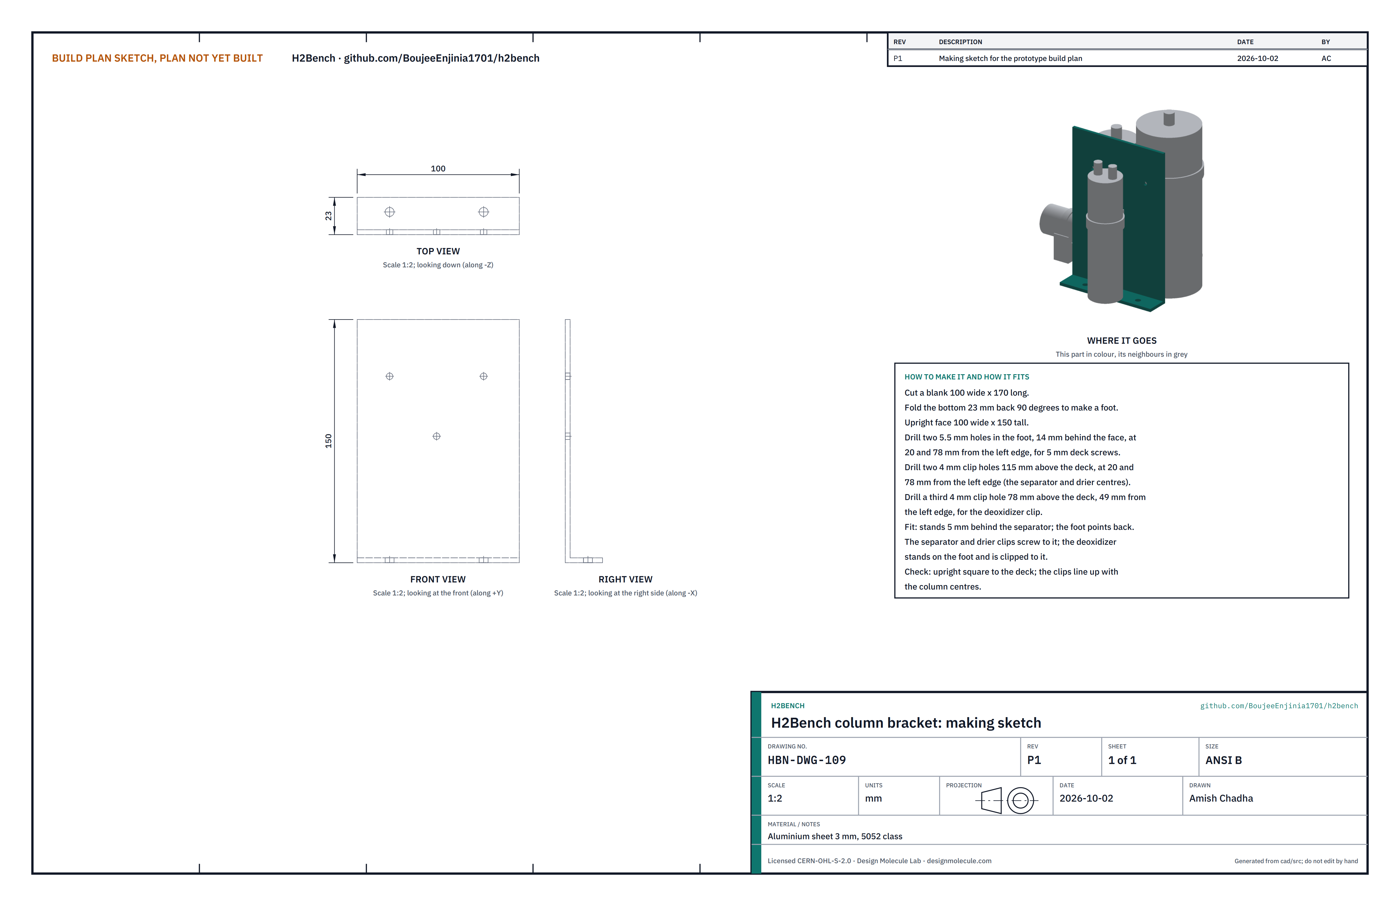
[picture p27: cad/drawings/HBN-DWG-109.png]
Figure 17. Making sketch of the column bracket


*Figure 17. Column bracket making sketch (HBN-DWG-109).*

**What it is and what it is made from.** An upright plate behind the separator and drier that their pipe clips screw to. Aluminium sheet 3 mm.

**How to make it.**

1. Cut a blank 100 wide x 170 long and fold the bottom 23 back 90 degrees to make a foot; the face is 150 tall.
2. Drill two 5.5 mm holes in the foot, 14 behind the face, at 20 and 78 from the left edge.
3. Drill two 4 mm clip holes 115 above the deck at 20 and 78 from the left edge, in line with the separator and drier centres, and a third 78 above the deck, 49 from the left edge, for the deoxidizer clip.

**How it fits the parts next to it.**

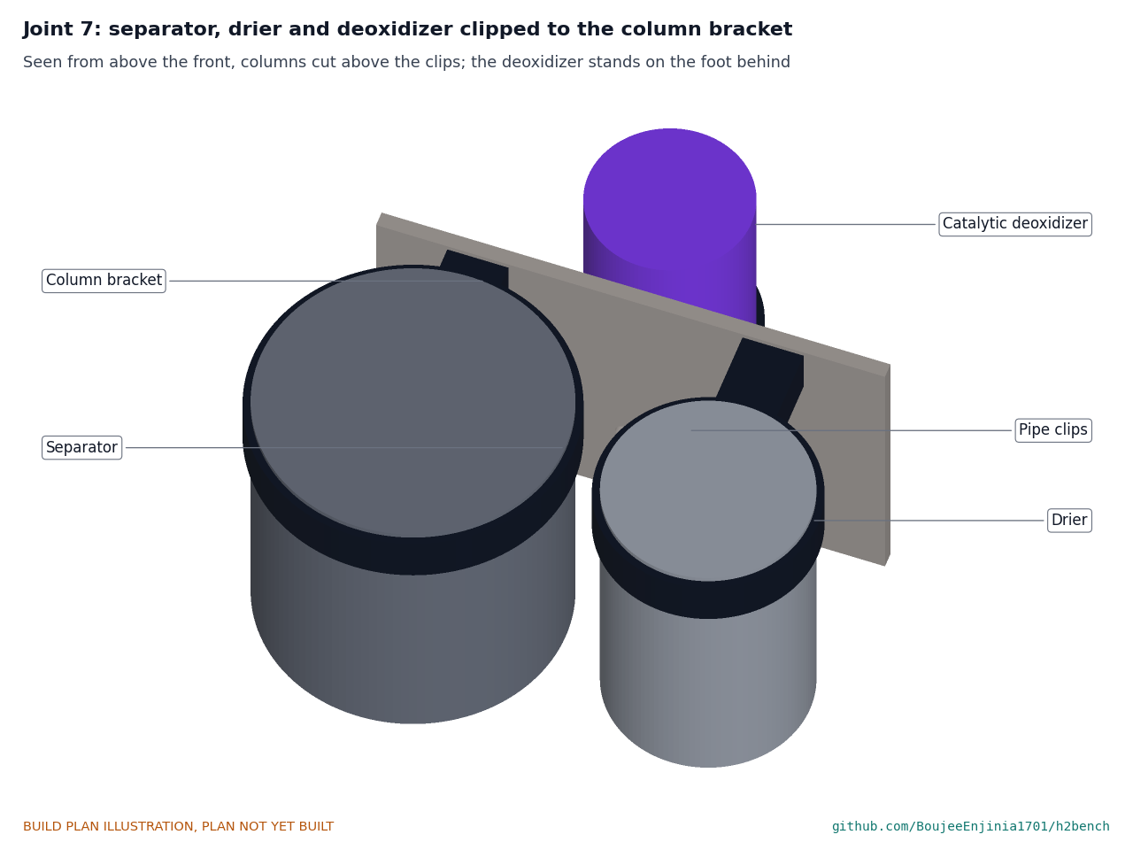
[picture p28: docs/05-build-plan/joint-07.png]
Figure 18. Joint 7: separator, drier and deoxidizer on the column bracket


*Figure 18. A 60 mm pipe clip round the separator, a 40 mm clip round the drier and a band clip round the deoxidizer, each screwed through the bracket.*

The bracket stands 5 behind the separator, its foot pointing back. The catalytic deoxidizer, a cartridge about 32 across and 120 tall with both gas ports on top, stands on the foot between the separator and the drier, 5 behind the plate, and a band clip round it screws to the plate at the third hole. The gas leaves the top of the separator, goes back and over to the deoxidizer's first port, and from its second port goes forward to the top of the drier.

**Check before moving on.** The face is square to the deck and the clips line up with the column centres; the deoxidizer stands upright on the foot with its clip snug and both ports on top.

### 3.10 Arrestor saddle

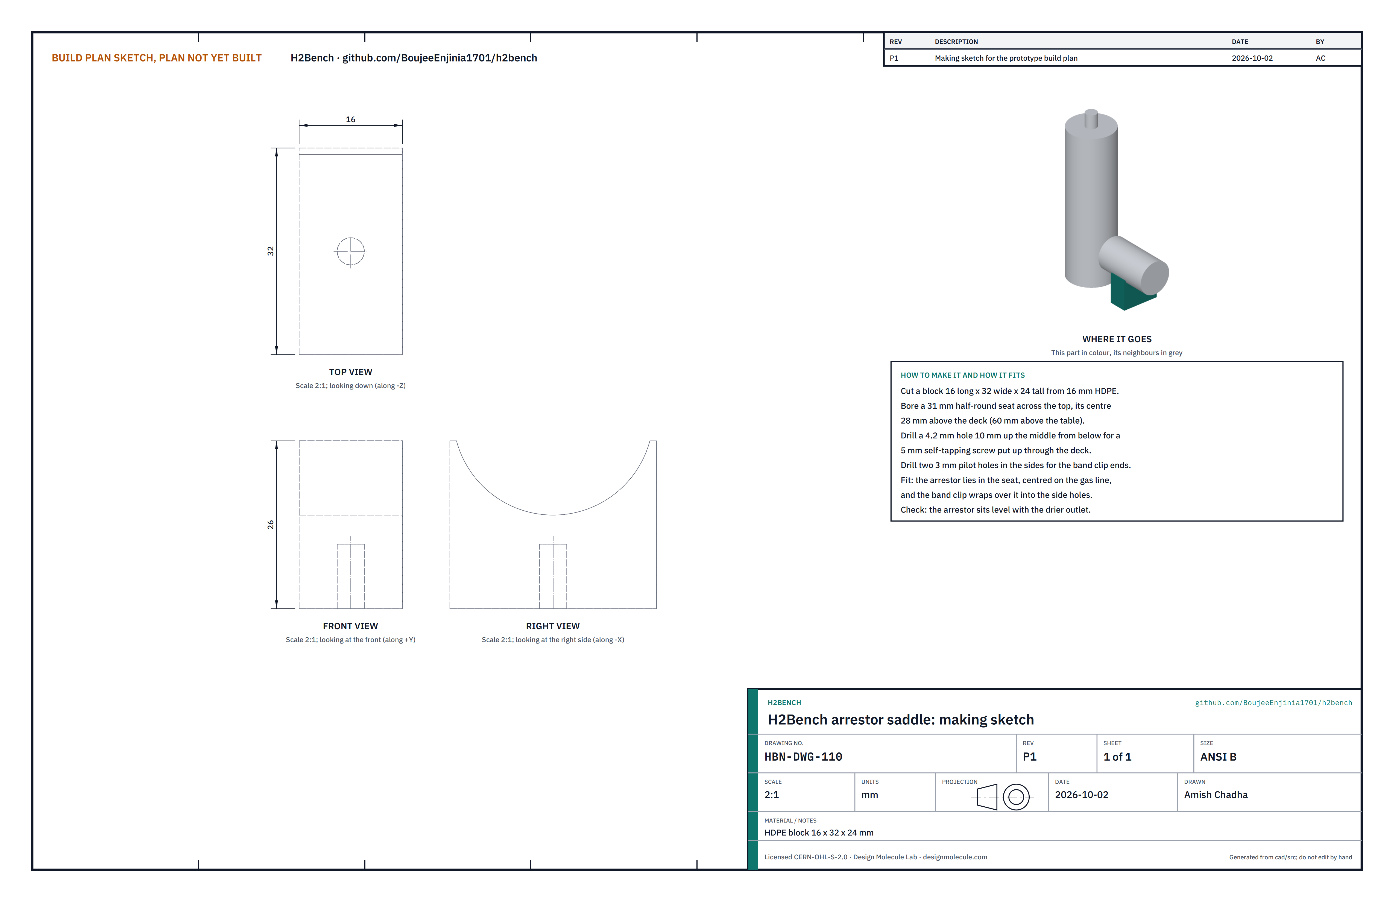
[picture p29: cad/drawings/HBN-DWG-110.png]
Figure 19. Making sketch of the arrestor saddle


*Figure 19. Arrestor saddle making sketch (HBN-DWG-110).*

**What it is and what it is made from.** A small block that the check valve and flame arrestor rest in. HDPE 16 mm, 16 x 32 x 24.

**How to make it.**

1. Cut the block 16 long x 32 wide x 24 tall.
2. Bore a 31 mm half-round seat across the top, its centre 28 above the deck.
3. Drill a 4.2 mm hole 10 up the middle from below for a 5 mm self-tapping screw put up through the deck, and two 3 mm pilot holes in the sides for the band clip ends.

**How it fits the parts next to it.**

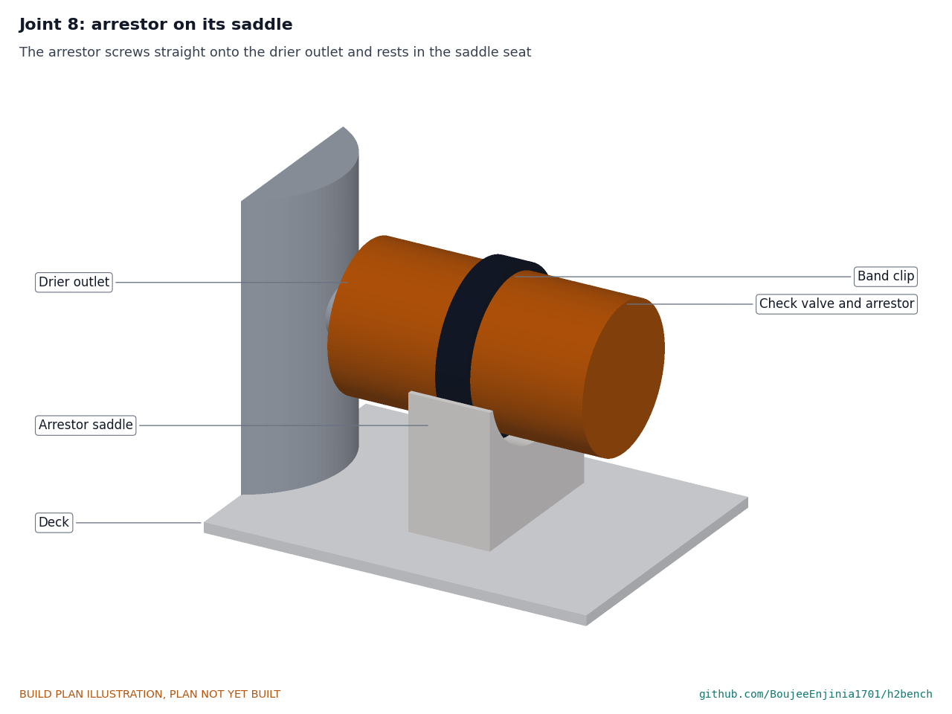
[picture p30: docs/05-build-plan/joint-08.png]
Figure 20. Joint 8: arrestor on its saddle


*Figure 20. The arrestor screws straight onto the drier outlet and rests in the seat under a band clip.*

**Check before moving on.** The arrestor sits level with the drier outlet and is not strained by its fittings.

### 3.11 Tank cradle

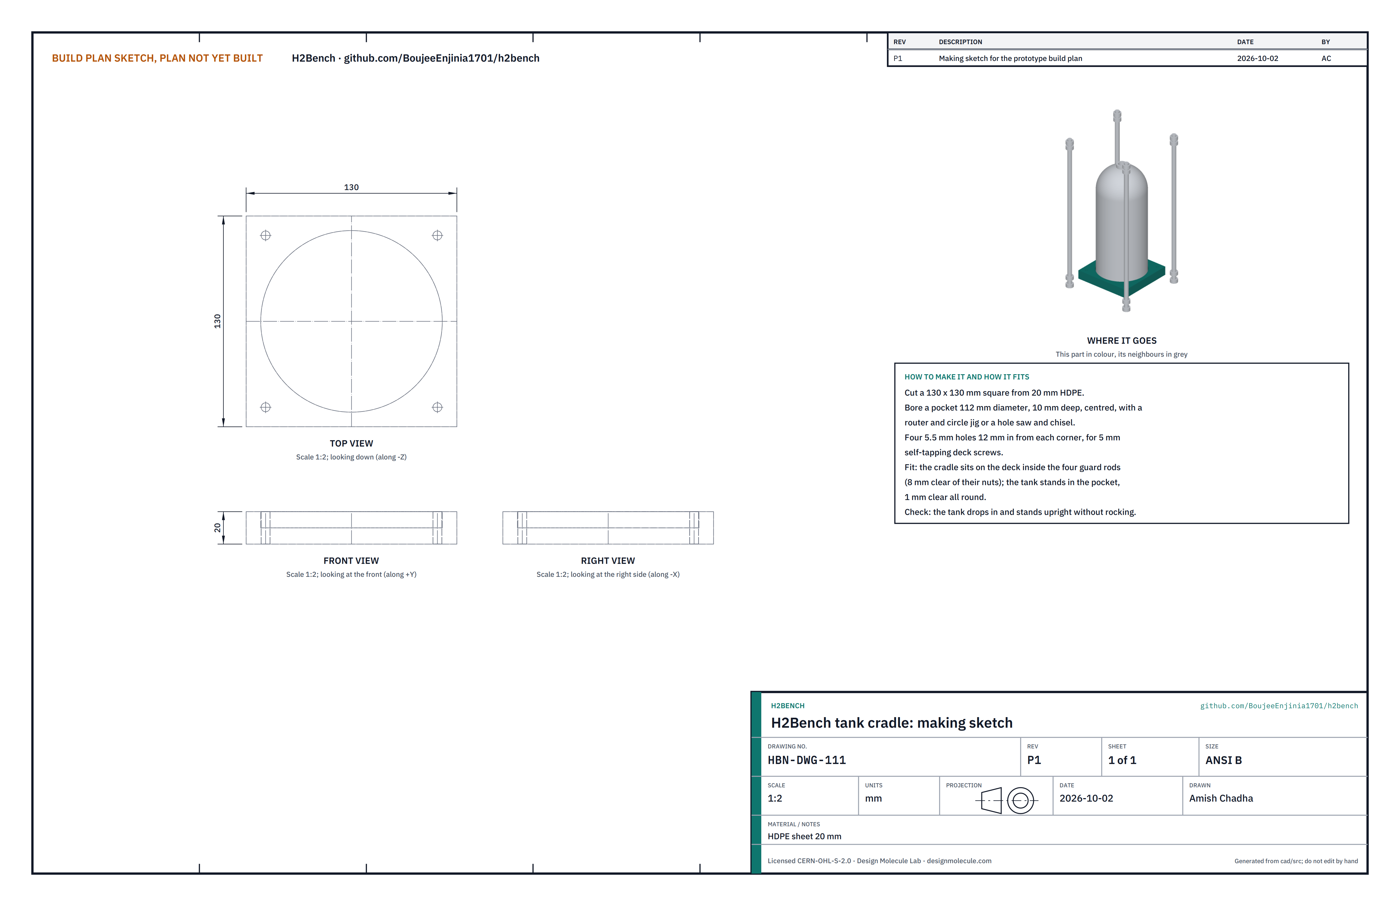
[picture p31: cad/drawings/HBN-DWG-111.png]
Figure 21. Making sketch of the tank cradle


*Figure 21. Tank cradle making sketch (HBN-DWG-111).*

**What it is and what it is made from.** A pocketed block the tank stands in. HDPE 20 mm, 130 x 130.

**How to make it.**

1. Cut a 130 square.
2. Bore a pocket 112 across and 10 deep, centred, with a router and circle jig (or a hole saw and chisel).
3. Drill four 5.5 mm holes 12 in from each corner.

**How it fits the parts next to it.**

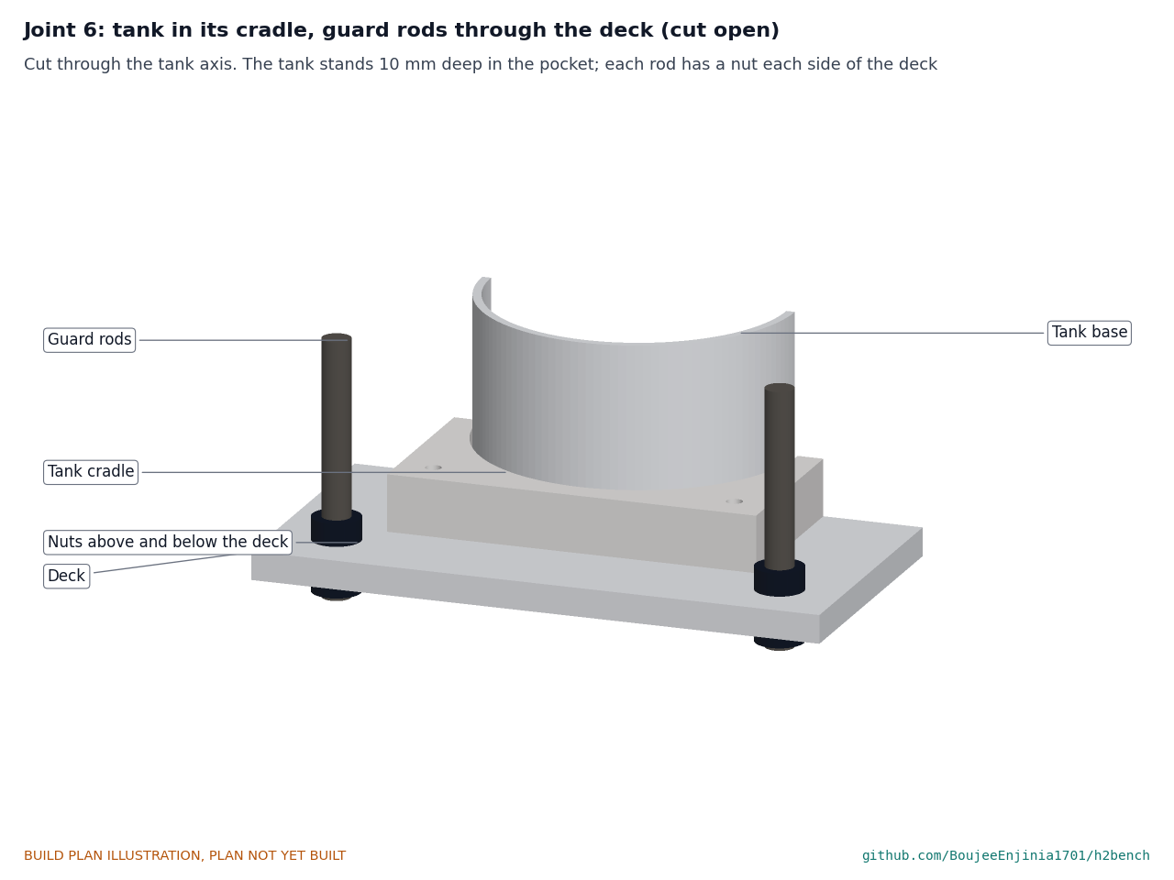
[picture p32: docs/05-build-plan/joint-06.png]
Figure 22. Joint 6: tank in its cradle and guard rods through the deck


*Figure 22. Cut through the tank axis. The tank stands 10 deep in the pocket, 1 clear all round; each guard rod screws into a tee nut under the deck and is locked by a nut above it.*

The cradle sits inside the four guard rods, 8 clear of their nuts.

**Check before moving on.** The tank drops in and stands upright without rocking.

### 3.12 Guard rods and top plate

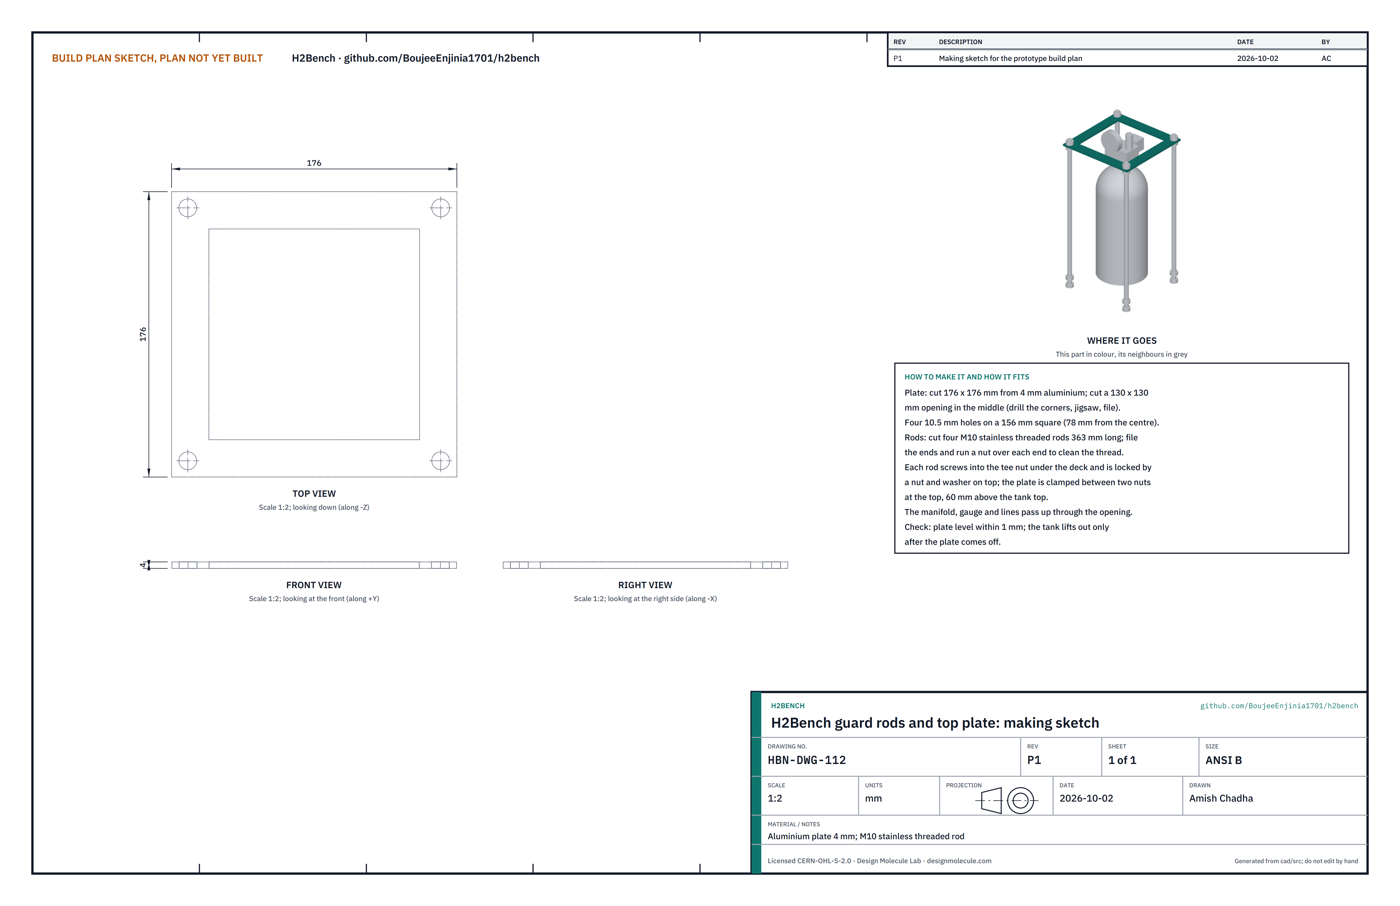
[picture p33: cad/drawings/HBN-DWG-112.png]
Figure 23. Making sketch of the guard rods and top plate


*Figure 23. Guard rods and top plate making sketch (HBN-DWG-112).*

**What it is and what it is made from.** The guard round the tank: four rods and a top plate. M10 stainless threaded rod; aluminium plate 4 mm.

**How to make it.**

1. Plate: cut 176 x 176; cut a 130 x 130 opening in the middle (drill the corners, cut with a jigsaw, file straight). Drill four 10.5 mm holes on a 156 square.
2. Rods: cut four lengths of 363. File the ends and run a nut over each end to clean the thread.

**How it fits the parts next to it.** Each rod screws into its tee nut and is locked with a nut and washer on the deck (Figure 22). The plate is clamped between two nuts on each rod, 60 above the top of the tank; the manifold, gauge and lines pass up through the opening.

**Check before moving on.** The plate is level within 1 mm, and the tank can be lifted out only once the plate is off.

### 3.13 Fuel cell bridge

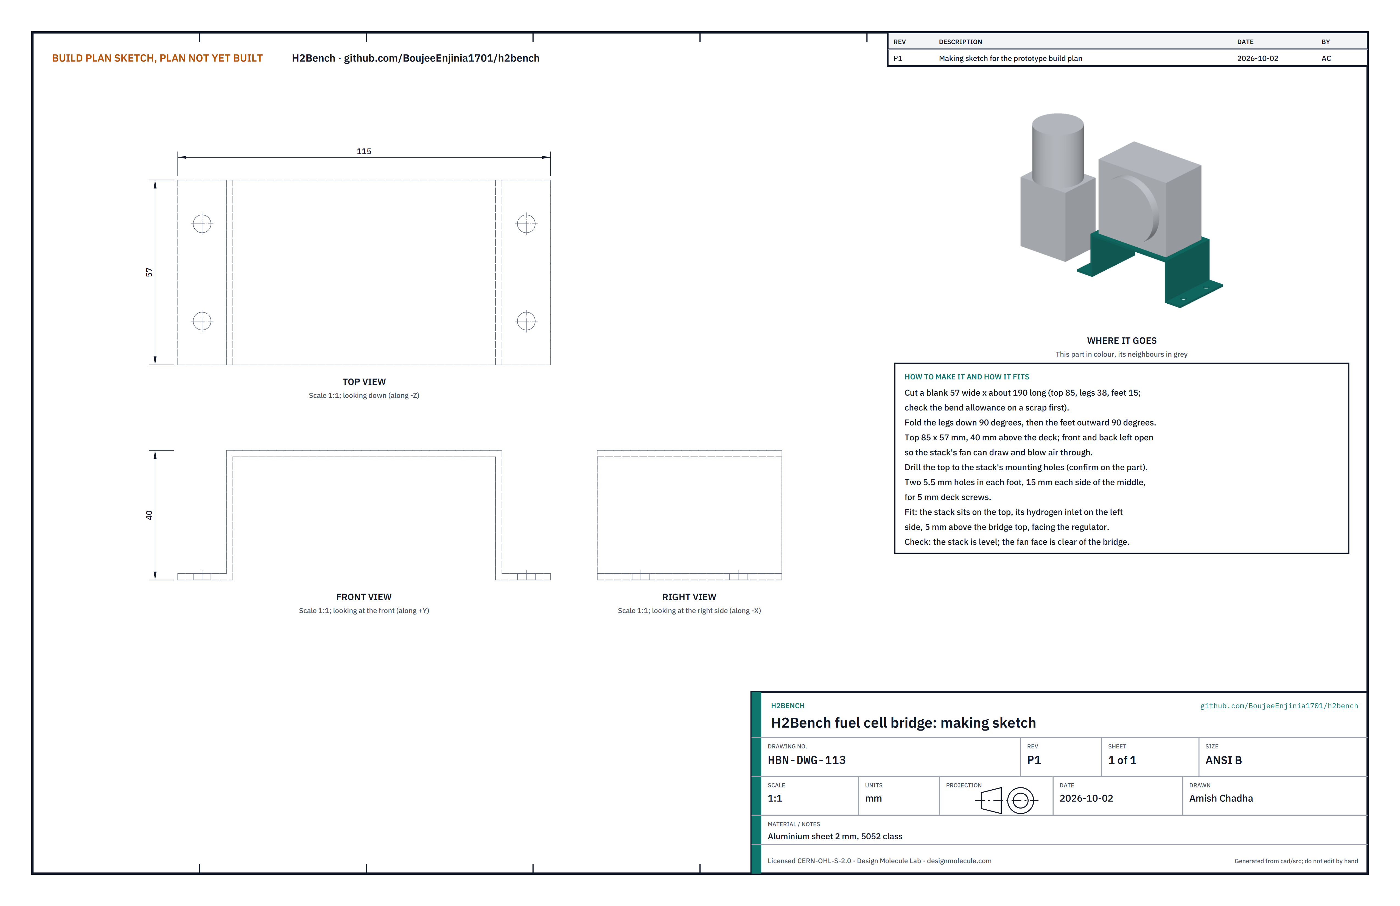
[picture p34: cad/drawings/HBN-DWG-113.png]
Figure 24. Making sketch of the fuel cell bridge


*Figure 24. Fuel cell bridge making sketch (HBN-DWG-113).*

**What it is and what it is made from.** A folded stand that lifts the fuel cell 40 mm, open at front and back so its fan can move air through the stack. Aluminium sheet 2 mm.

**How to make it.**

1. Cut a blank 57 wide x about 190 long (top 85, legs 38, feet 15); check the bend allowance on a scrap first.
2. Fold the legs down 90 degrees, then the feet outward 90 degrees.
3. Drill the top to the stack's mounting holes, and two 5.5 mm holes in each foot, 15 each side of the middle.

**How it fits the parts next to it.** The stack sits on the top with its hydrogen inlet on the left side, facing the regulator, 5 above the bridge top.

**Check before moving on.** The stack is level and its fan face is clear of the bridge.

### 3.14 Bought components, lines and wiring

Buy to specification, not brand. Line numbers are those of the bill of materials.

- **Bench power supply (line 4).** Lab supply 0 to 30 V, 0 to 10 A, constant-current mode, earthed, with a plug-in 30 mA RCD (line 18).
- **Reservoir and deionizer (line 5).** 500 mL HDPE reservoir about 110 across and 170 tall with a low side outlet and a vented lid; mixed-bed resin cartridge with color change, about 50 across and 150 tall, with 6 mm fittings; conductivity check to 1 µS/cm.
- **Electrolyzer (line 6).** 4-cell PEM stack, about 7.8 V at 9 A, end plates about 110 square, hydrogen side rated to 332 kPa or more over the oxygen side, two mounting holes in each end plate, water in and oxygen out on one end plate.
- **Separator and drier (line 7).** Separator column about 60 across and 160 tall with a drain valve at its foot, drained by hand only at the 20 kPa gauge holding pressure, under the hood, with H2Guard running; 50 g indicating silica gel drier about 40 across and 130 tall; both rated 1 MPa or more.
- **Catalytic deoxidizer (line 19).** Palladium-catalyst cartridge about 32 across and 120 tall with two 6 mm compression ports on top, rated 1 MPa or more, and one band clip. It warms slightly while it works and is never covered. Keep it in the line unless the stack supplier's data show the oxygen in the hydrogen is within the fuel cell's 99.995 % purity limit at the lowest operating current.
- **Check valve and flame arrestor (line 8).** Stainless check valve, 7 kPa cracking, and a sintered flame arrestor rated for hydrogen, joined in line, about 28 across and 50 long.
- **Tank (line 9).** 2 L certified aluminium cylinder (6061-T6 class), stamped for 1 MPa working pressure or more, flat base 106 to 111 across so it sits in the 112 pocket of the cradle, threaded neck that takes the manifold adapter. Match the neck thread to the adapter before you buy.
- **Tank manifold (line 10).** Neck adapter carrying a 0 to 600 kPa absolute transducer, a 10 kΩ thermistor bonded to the shell, a relief valve set to 325 kPa gauge, a 0 to 600 kPa gauge, a needle valve set so venting 300 to 20 kPa gauge takes 3 min or more, and a pressure switch set to open at 310 kPa gauge.
- **Regulator and solenoid (line 11).** Regulator 0 to 100 kPa out, set near 50 kPa gauge; 12 V normally closed solenoid on the tank outlet.
- **Fuel cell (line 12).** Air-cooled PEM stack, 12 W class, 13 cells, about 75 x 47 x 70, with fan and purge valve.
- **Load and lamp (line 13), meters and logger (line 14).** Constant-current load 0 to 3 A with a 5 W LED lamp; logger board with three power monitors and shunts, pressure and temperature inputs, a 3.5 in display, and a 12 V relay rated 10 A DC or more.
- **Lines and fixings (lines 16 and 17).** PTFE or polyamide tubing 6 mm and compression fittings rated for hydrogen; 2.5 mm² wire for the electrolyzer supply; stainless M4, M5 and M6 fasteners, M10 tee nuts and nuts, drop-in T-nuts, 5 mm self-tapping screws, silicone sealant, hazard and flow-direction labels.

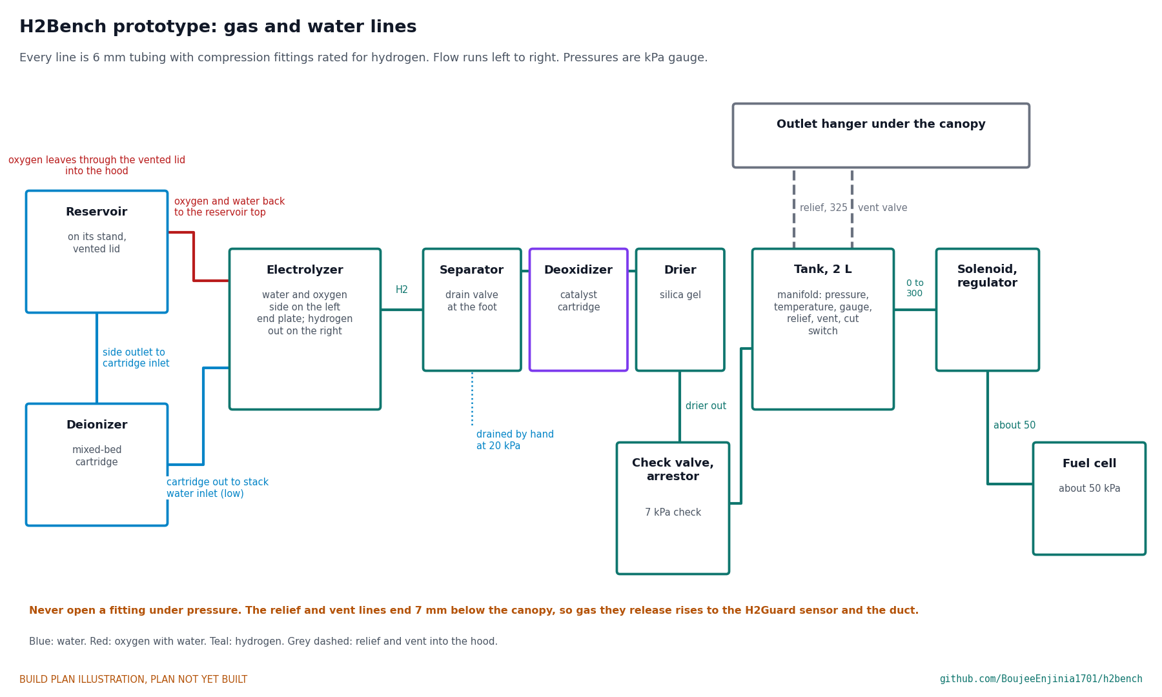
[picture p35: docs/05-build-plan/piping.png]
Figure 25. Gas and water lines


*Figure 25. Gas and water lines, block level.*

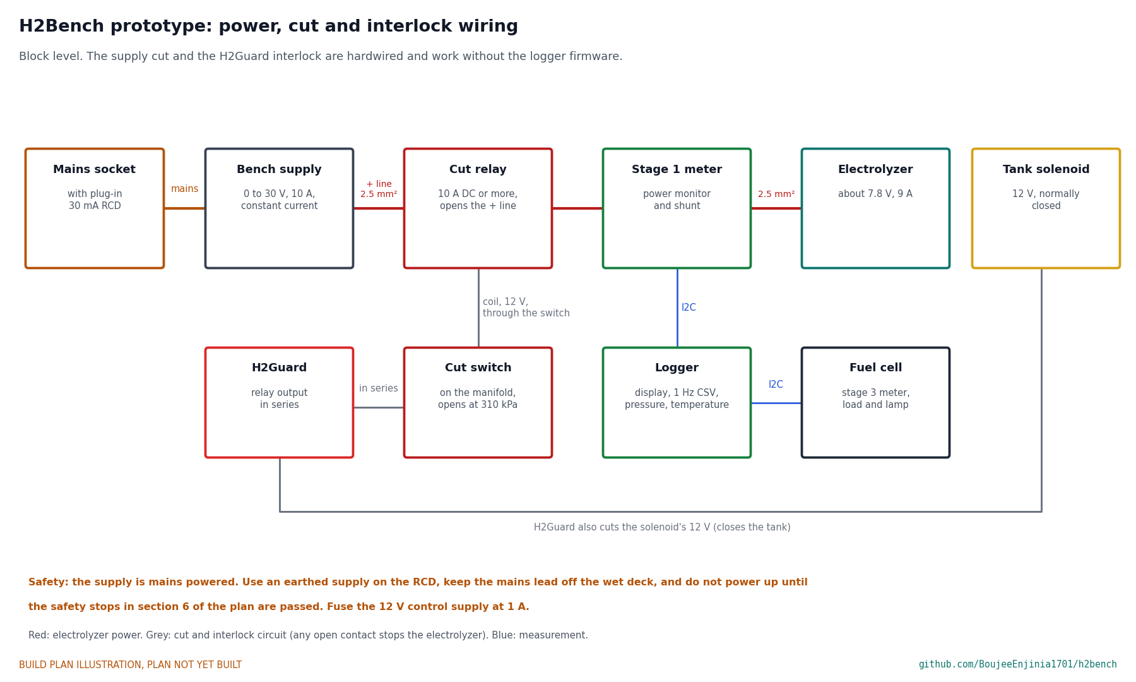
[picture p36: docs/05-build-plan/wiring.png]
Figure 26. Power, cut and interlock wiring


*Figure 26. Power, cut and interlock wiring, block level. No circuit board is laid out at this stage; bought modules stand in for it.*

The pressure switch on the manifold and the H2Guard relay output are wired in series in the coil circuit of the cut relay, which breaks the positive line from the bench supply to the electrolyzer: any open contact stops the electrolyzer, with no software in the path. H2Guard also breaks the 12 V supply to the normally closed tank solenoid, which closes the tank.

## 4. Putting it together

In each picture the parts already fitted are grey and the parts being fitted are in colour, with an arrow showing the way they go in.

### Step 1: frame rails and corner brackets

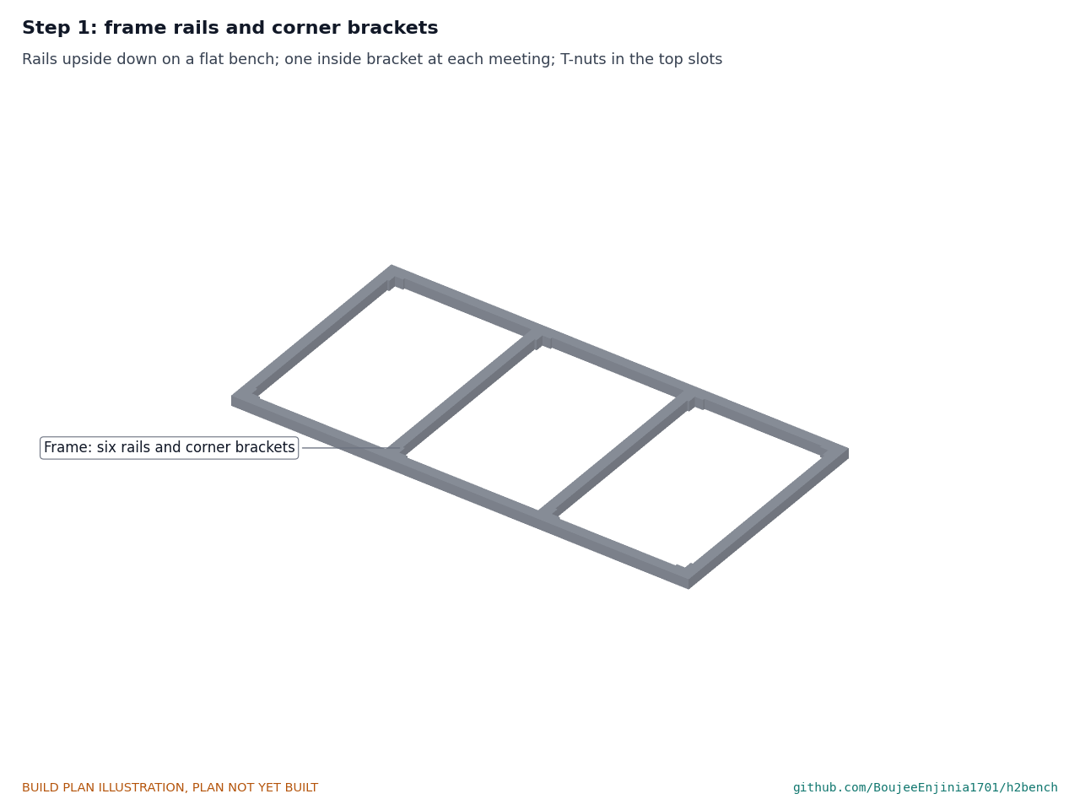
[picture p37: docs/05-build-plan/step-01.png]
Step 1


Rails upside down on a flat bench; one inside bracket at each meeting; T-nuts in the top slots before each joint closes. Turn the frame right way up.

### Step 2: deck, water post and drip lip

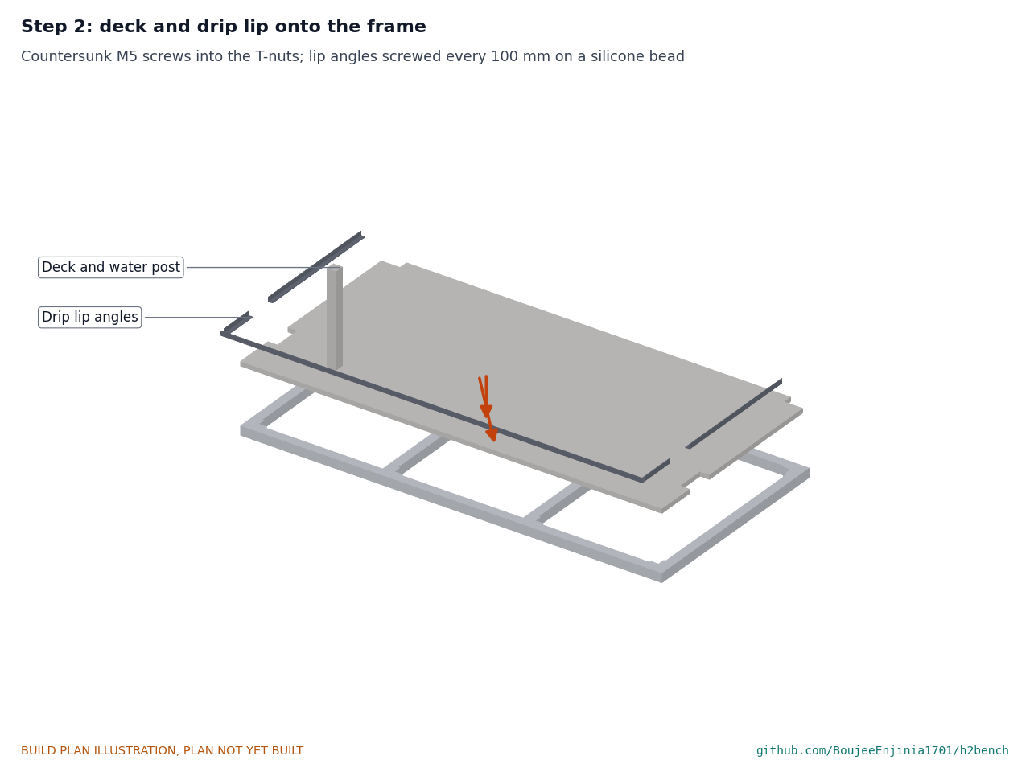
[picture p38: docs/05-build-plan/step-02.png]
Step 2


Fit the guard-rod tee nuts and the water post to the deck first (section 3.2). Then lay the deck on the frame and fix it with countersunk M5 screws into the T-nuts. Screw the lip angles down every 100 mm on a bead of silicone.

### Step 3: posts onto the frame

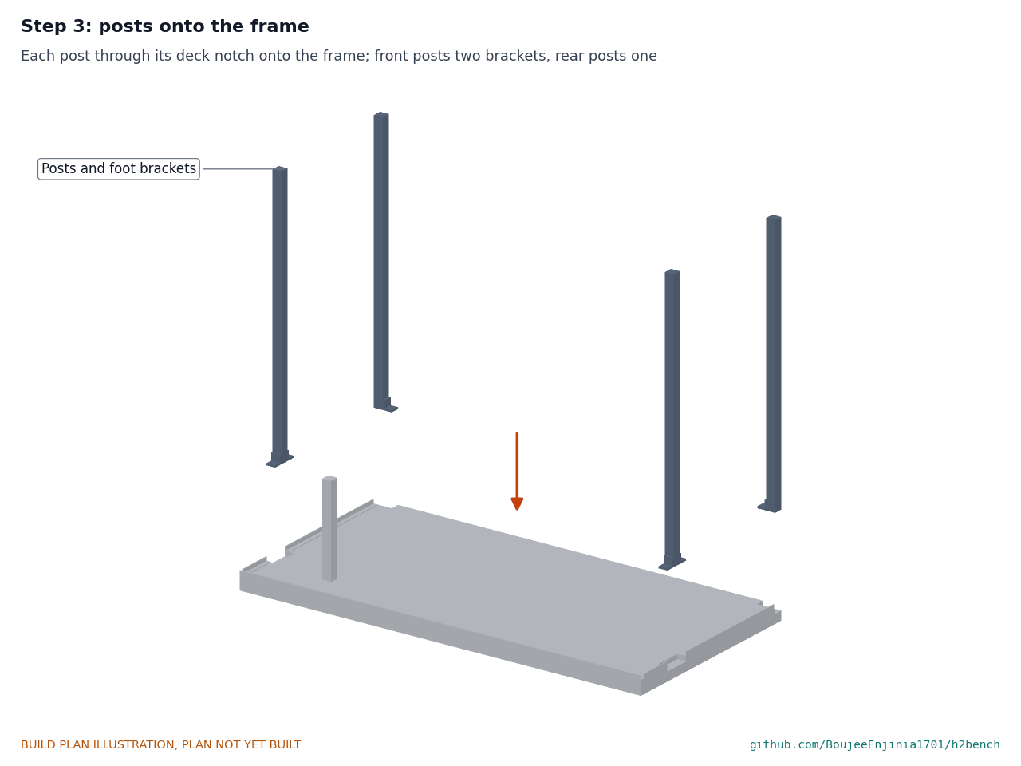
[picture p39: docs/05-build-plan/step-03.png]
Step 3


Each post stands through its deck notch onto the frame. Front posts: one bracket in front and one behind, on the end rail. Rear posts: one bracket on the inner side, on the back rail. Square each post before tightening.

### Step 4: instrument panel and top frame

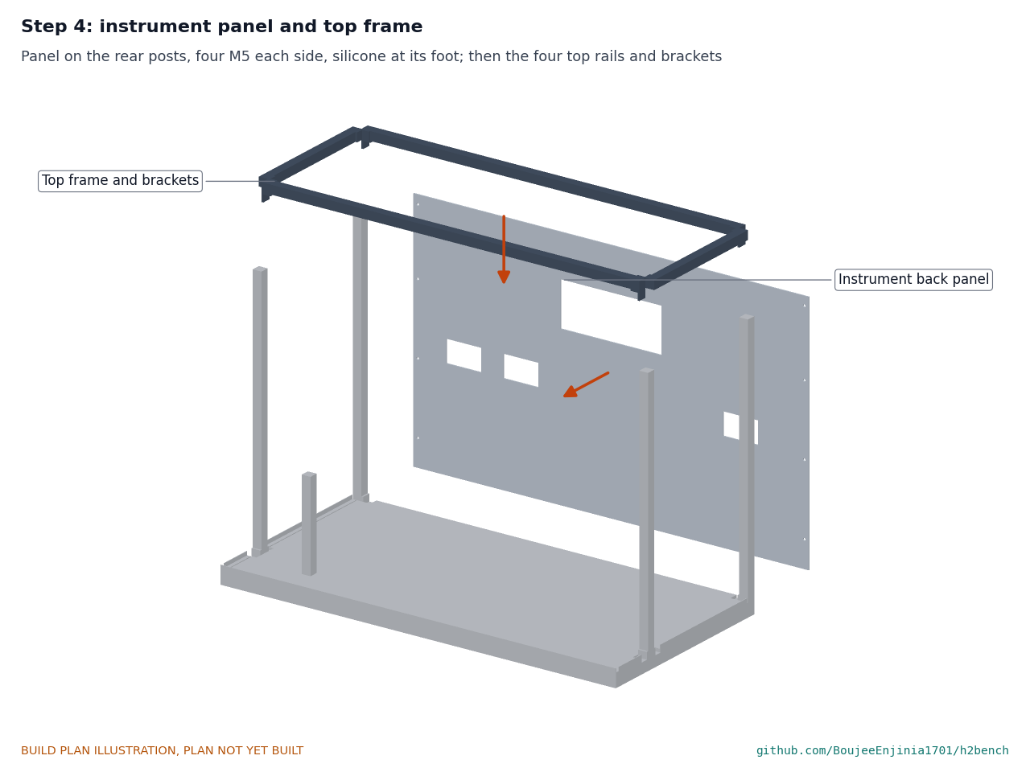
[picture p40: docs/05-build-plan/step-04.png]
Step 4


Run a bead of silicone along the deck where the panel stands, set the panel against the rear posts and fit four M5 button-head screws each side. Then fit the four top rails and their eight brackets, flush with the post tops.

### Step 5: canopy, duct collar and outlet hanger

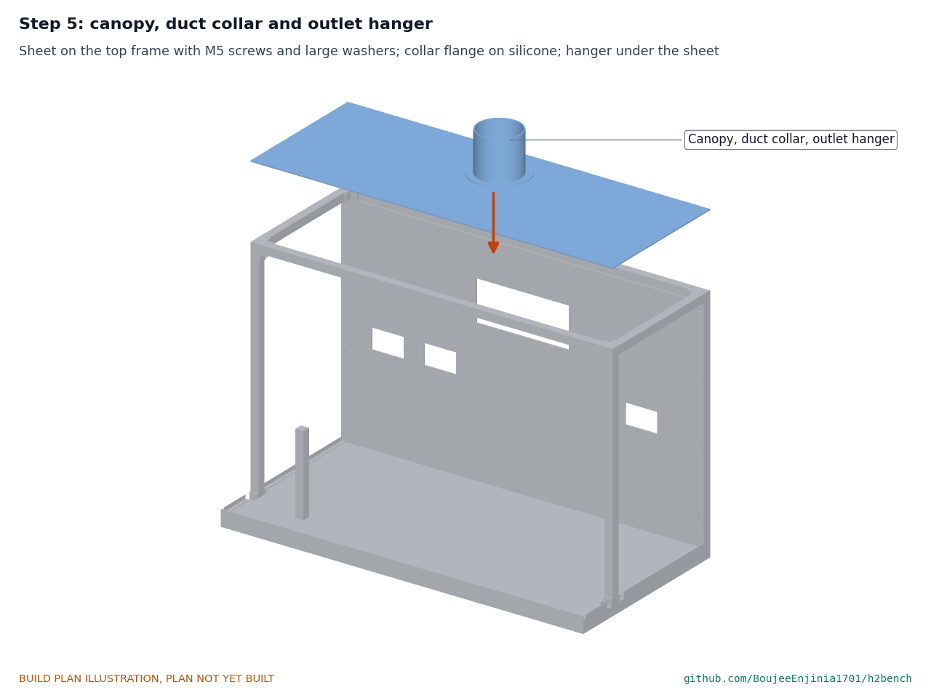
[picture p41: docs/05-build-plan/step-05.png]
Step 5


Screw the hanger under the sheet, then lay the sheet on the top frame and fit twelve M5 screws with large washers, snug, not tight. Fit the duct collar through its hole, flange on a bead of silicone, four M4 screws.

### Step 6: reservoir stand, reservoir and cartridge

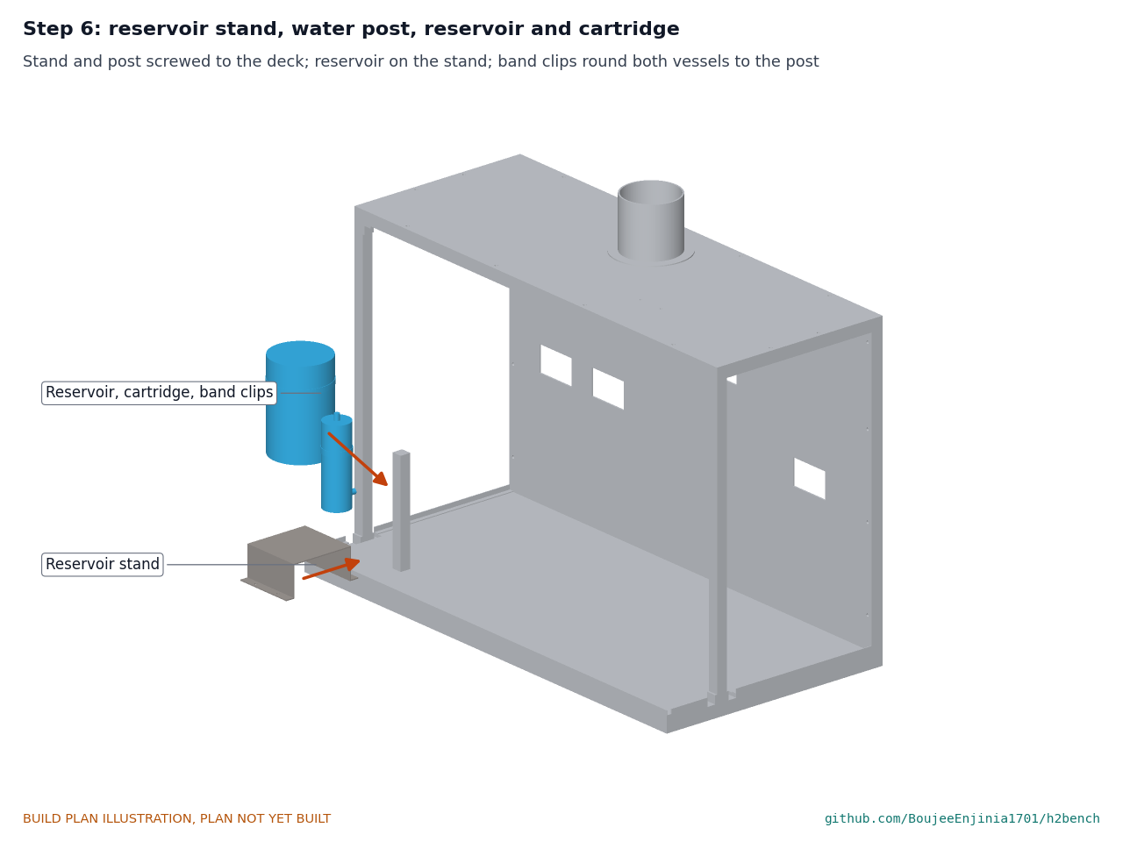
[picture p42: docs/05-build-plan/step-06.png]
Step 6


Screw the stand down (Table 2). Stand the reservoir on it and the cartridge on the deck beside the water post; fit a band clip round each to the post.

### Step 7: electrolyzer on its feet

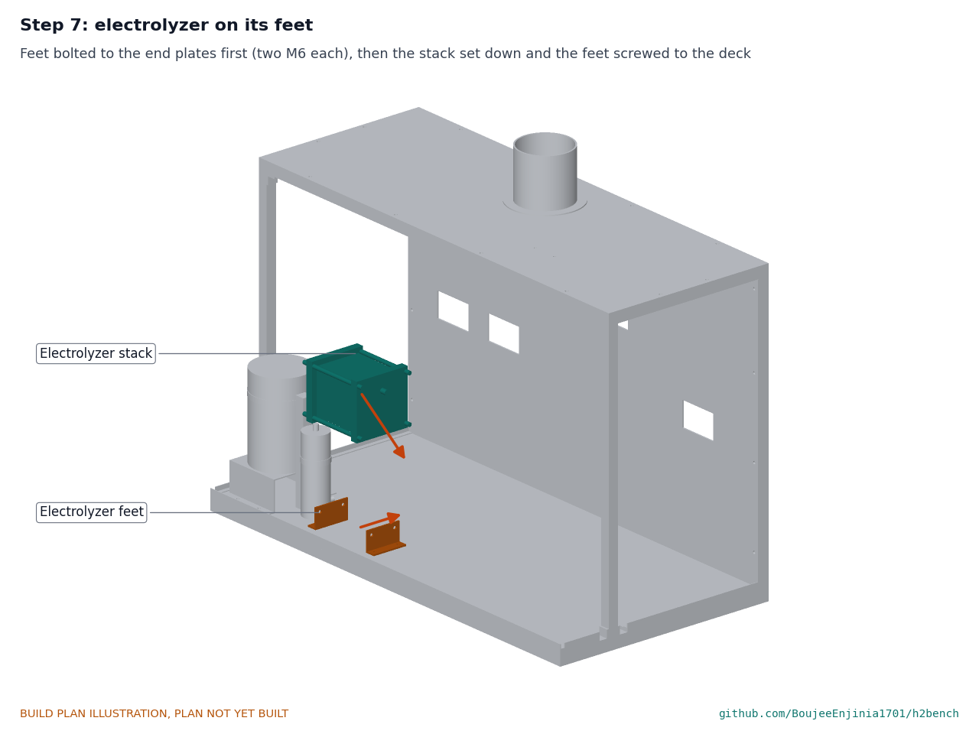
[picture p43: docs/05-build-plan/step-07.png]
Step 7


Bolt the feet to the end plates first, two M6 each. Set the stack down with its hydrogen outlet to the right and its water ports to the back, and screw the feet to the deck.

### Step 8: column bracket, separator, deoxidizer, drier and arrestor

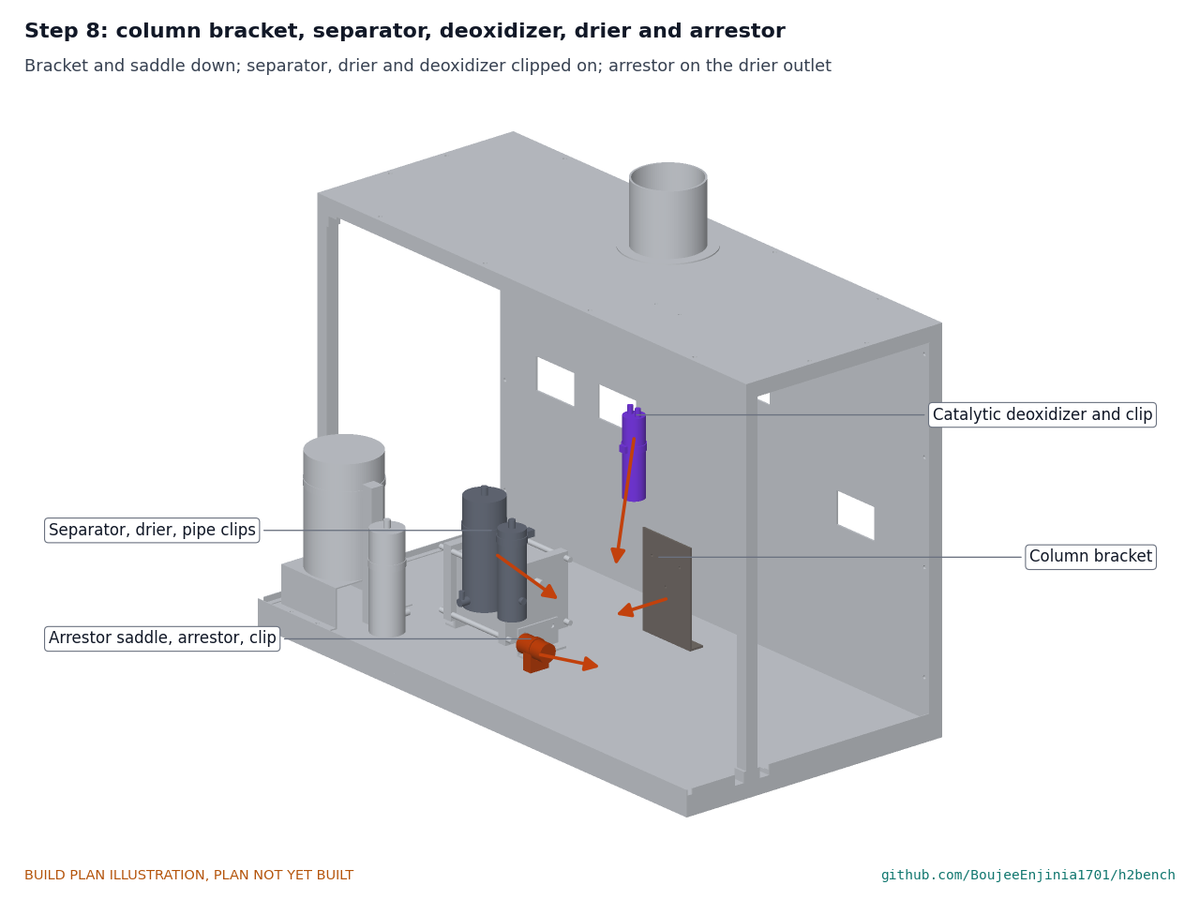
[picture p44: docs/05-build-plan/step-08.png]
Step 8


Screw the column bracket and the arrestor saddle down. Clip the separator and drier to the bracket. Stand the deoxidizer on the bracket foot between them and clip it to the plate. Screw the check valve and arrestor onto the drier's outlet, arrow toward the tank, and close the band clip over it.

### Step 9: cradle, guard rods and tank

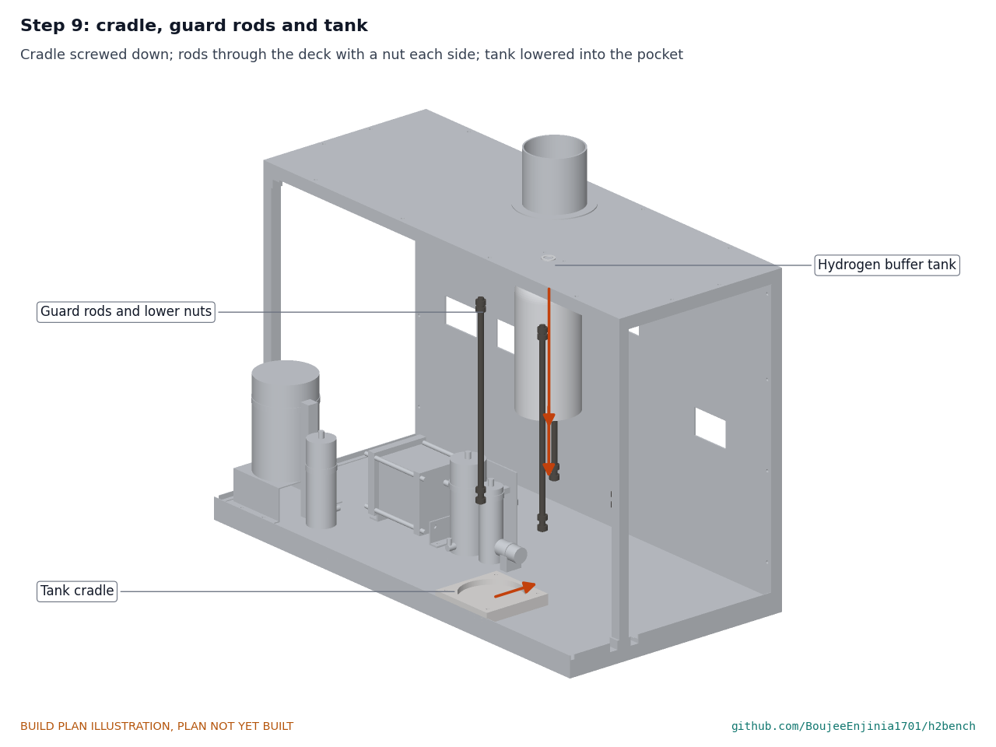
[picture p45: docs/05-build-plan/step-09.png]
Step 9


Screw the cradle down. Screw each rod into its tee nut and lock it with a nut and washer on the deck. Lower the tank into the pocket, neck up.

### Step 10: tank manifold and guard top plate

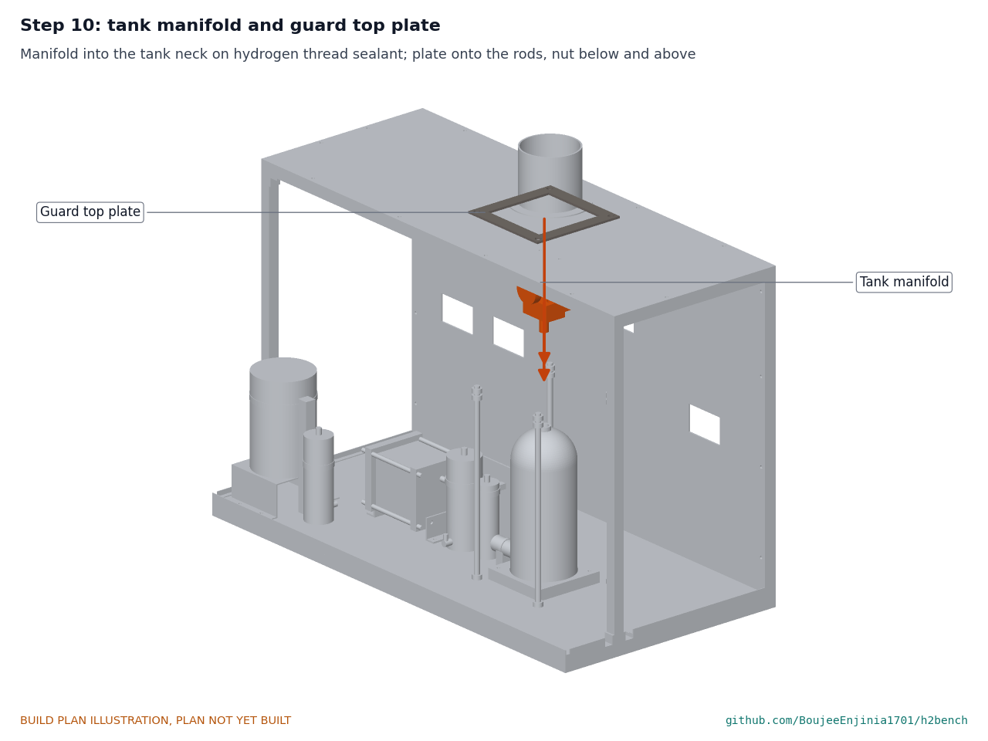
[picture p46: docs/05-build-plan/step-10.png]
Step 10


Screw the manifold into the tank neck on thread sealant rated for hydrogen, gauge to the front, cut switch to the back. Run a nut down each rod to 56 above the tank top, drop the plate on, and fit a nut above it.

### Step 11: regulator, fuel cell and load

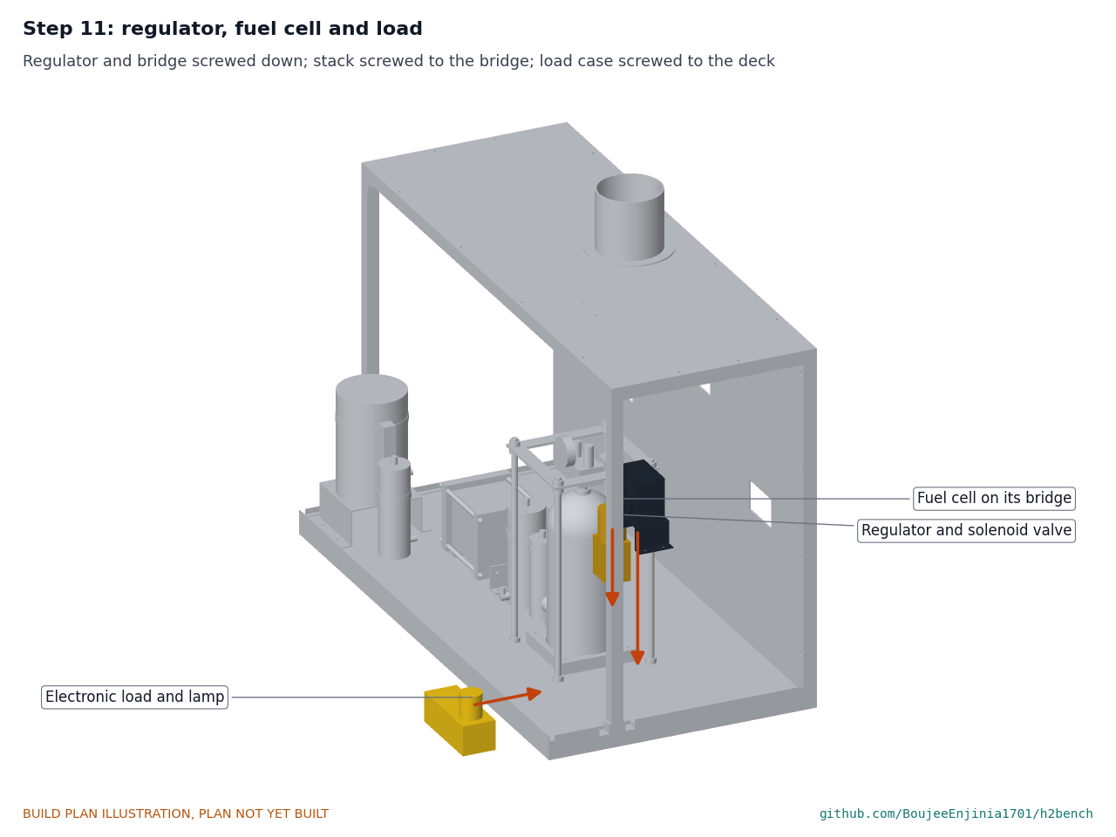
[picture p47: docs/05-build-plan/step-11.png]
Step 11


Screw the regulator and the fuel cell bridge down, then the fuel cell to the bridge, hydrogen inlet to the left. Screw the load case to the deck at the front right.

### Step 12: gas and water lines

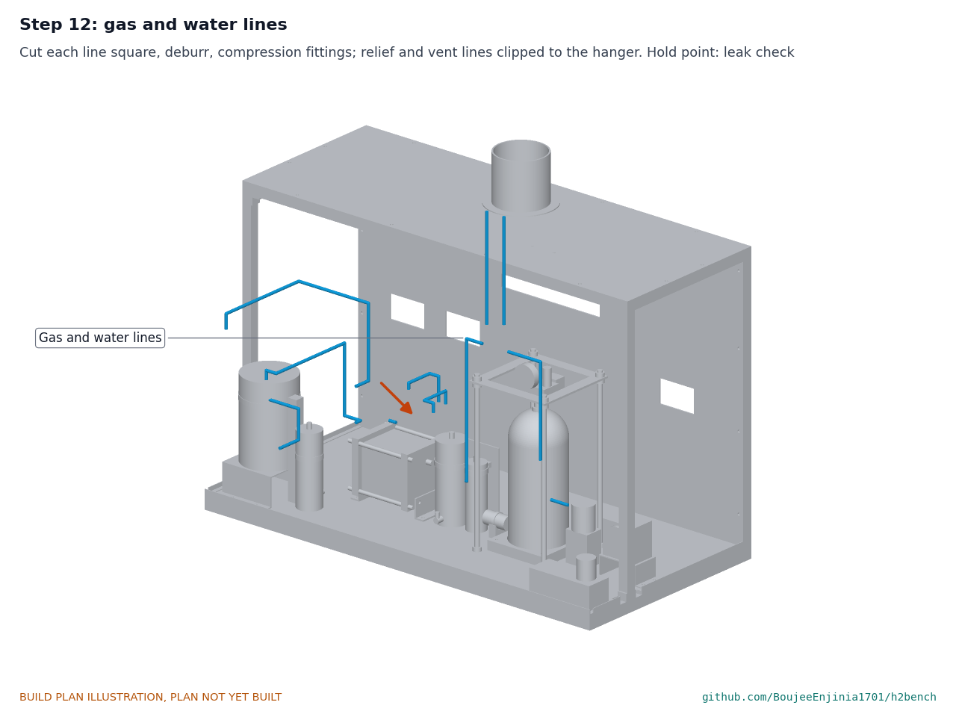
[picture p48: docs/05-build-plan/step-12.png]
Step 12


Fit every line as Figure 25 shows: cut each tube square, deburr it, fit the inserts and compression nuts, and keep every gas line at least 5 clear of the tank. The line from the separator top runs back to the deoxidizer's first port, and a second line runs from its other port forward to the drier top, over the bracket plate and at least 5 above it. Clip the relief and vent lines to the hanger, ends 7 below the canopy. Label each line with its flow direction. **Hold point:** the leak checks of safety stop S3.

### Step 13: power supply, meters and wiring

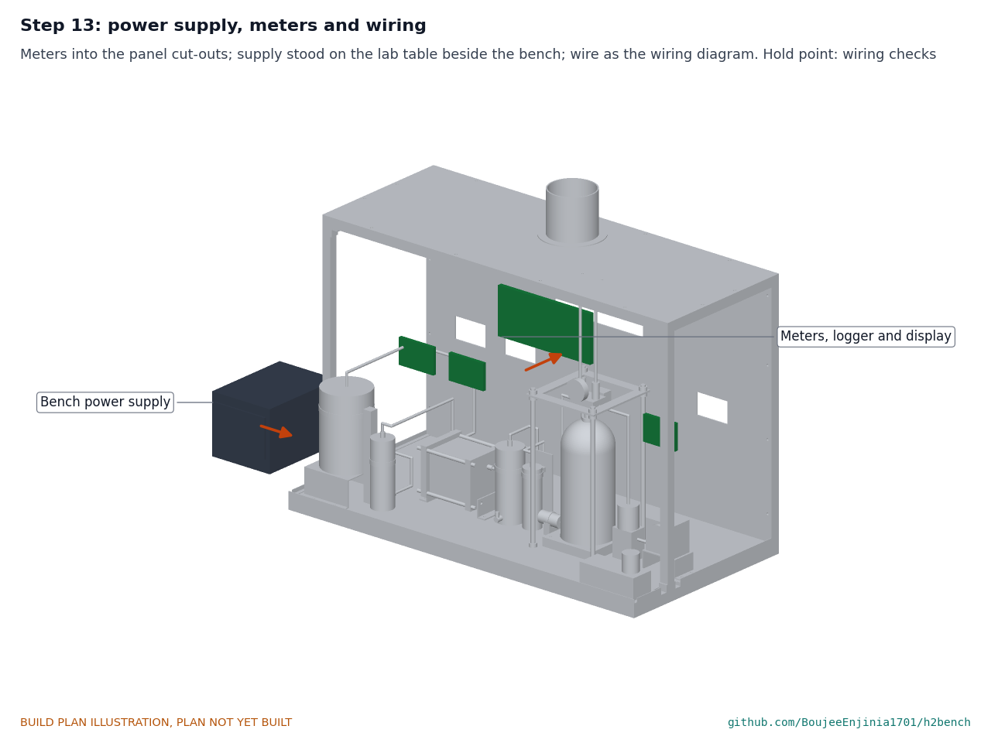
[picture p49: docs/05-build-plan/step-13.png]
Step 13


Fit the meters and display into the panel openings and the logger behind the panel. Stand the supply on the lab table beside the left end of the bench, at least 20 from the bench, with the mains lead routed clear of the bench and any water. Wire as Figure 26 with the supply switched off and unplugged. **Hold point:** the wiring checks of safety stop S2.

### Step 14: H2Guard sensor, fan and controller

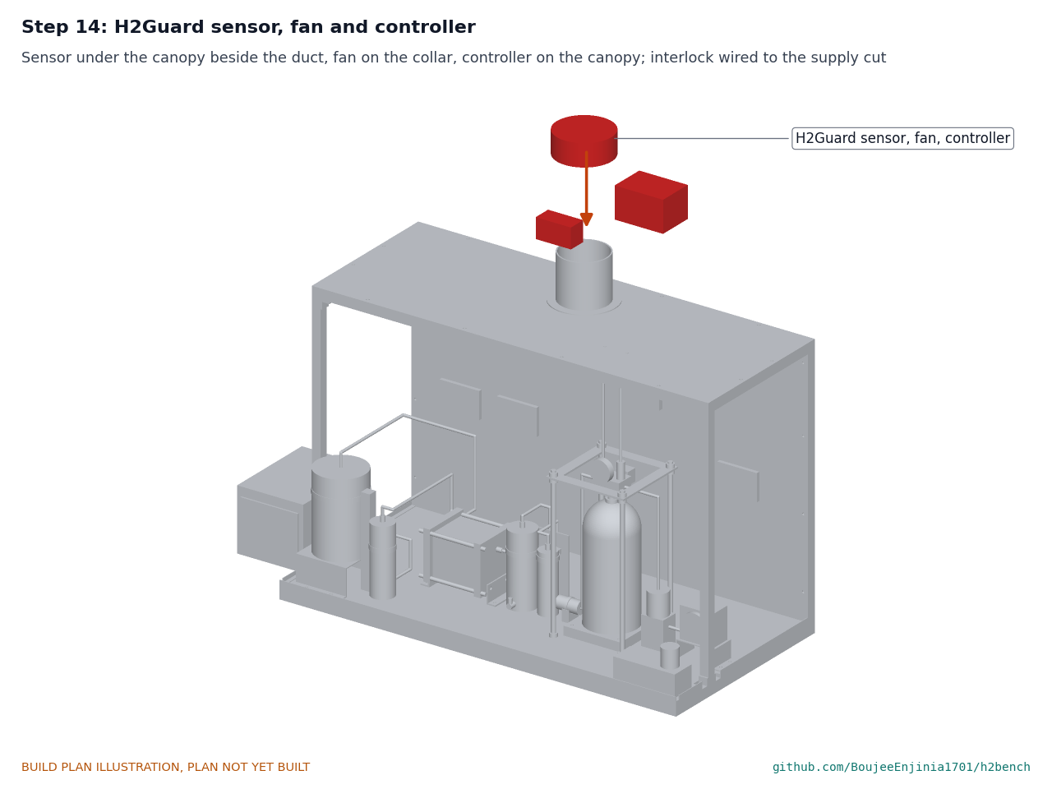
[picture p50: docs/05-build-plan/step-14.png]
Step 14


Fit the H2Guard sensor under the canopy beside the duct, the fan on the collar and the controller on the canopy, as the H2Guard project describes. Wire its relay output in series with the cut switch and in the solenoid supply (Figure 26). **Hold point:** safety stop S4.

## 5. First checks

These are the checks a TRL 4 test report would record; this plan only lists them. Requirement numbers are those of HBN-REQ-001.

*Table 3. First checks.*

| Check | Requirement | How | Pass when |
| --- | --- | --- | --- |
| Size and mass | R13 | Measure the envelope; weigh the bench with and without the supply | Within 1,000 x 500 x 800 mm; mass recorded against 25 kg |
| Guard and lines | R15 | Look at the guard and every line end | Tank inside the guard, top plate on; relief and vent lines end under the canopy; no fitting opens without a tool |
| Water quality | R11 | Conductivity at the stack inlet after the cartridge | 1 µS/cm or less |
| Leak tightness | R5, R7 | Nitrogen at 300 kPa gauge for 30 min, soapy water on every fitting (S3) | No bubbles; pressure fall within the transducer's resolution after temperature correction |
| Supply cut | R6 | Raise the manifold pressure with nitrogen to the switch point while watching the relay (S3) | The relay opens at 310 kPa gauge, give or take 5 |
| Relief valve | R6 | Bench test of the relief valve before fitting | Lifts at 325 kPa gauge, give or take 10 |
| Interlock | R8 | H2Guard test input or test gas at the sensor with the supply on a dummy load (S4) | Supply cut and solenoid closed within 2 s; fan runs |
| Electrolyzer power | R3 | Constant current 9 A, first fill (S5) | 100 W or less at the stack |
| Fill and cycle time | R2 | Time one fill from 70 to 300 kPa gauge and one discharge | Fill plus discharge within 60 min |
| Fuel cell output | R4 | Lamp load at 1.5 A (S6) | 10 W or more net |
| Logging | R12 | Log one cycle | Voltage, current, power, pressure and temperature at 1 Hz in a CSV file |
| Measurement | R1 | Hydrogen counted by gas law and by charge for three fills | Stage efficiencies repeat within 5 % relative |
| Vent and shutdown | R16 | Vent 300 to 20 kPa gauge through the needle valve; time a full setup and shutdown | Vent 3 min or more; bench safe within 5 min; setup within 15 min |

## 6. Safety stops

Stop at each point. Carry on only when everything listed is true.

- **S1. Before any work with the parts.** The workspace has a fire extinguisher for electrical fires, a clear route out, and no open flames, heaters or sparking tools near the bench. Safety glasses and gloves for cutting and drilling.
- **S2. Before the bench supply is plugged in.** The supply is earthed and plugged into the 30 mA RCD, which trips on its test button. The mains lead runs off the deck. With the supply off, the cut relay is open whenever the cut switch or the H2Guard contact is open (meter check). Wire sizes and polarity are checked against Figure 26.
- **S3. Before any gas pressure.** Every fitting is tight and labelled. Leak test with nitrogen, not air or hydrogen: 50 kPa gauge first, then 300 kPa gauge, soapy water on every fitting, 30 min hold. Check the cut switch at 310 kPa gauge with nitrogen. Vent the nitrogen through the needle valve, never by opening a fitting.
- **S4. Before any hydrogen is made.** H2Guard is fitted and tested: its alarm, its cut of the electrolyzer supply and its close of the tank solenoid all work within 2 s, and the fan extracts through the duct to outdoors. The relief valve has been bench tested. A trained supervisor is present.
- **S5. First fill.** Purge the tank of nitrogen and air by three fill and vent cycles to 300 kPa gauge, venting slowly through the needle valve each time (3 min or more). Attended the whole time, hood fan running. Stop at any H2Guard warning, any smell of burning, or any pressure above 300 kPa gauge that the cut does not stop. Keep the tank above 20 kPa gauge from then on so air cannot enter.
- **S6. Before the fuel cell runs.** The deoxidizer is fitted between the separator and the drier, and the fuel cell supplier has accepted the gas the bench makes. The regulator is set to about 50 kPa gauge with the solenoid closed and the fuel cell disconnected.
- **S7. Before students use the bench.** All first checks of section 5 are recorded; the supervisor knows the vent, purge and shutdown sequence; the room meets the site's hydrogen risk assessment.

## 7. Tools, skills and workspace

**Tools.** Hacksaw with a 24 teeth per inch blade, or a mitre saw with a non-ferrous blade; bench vice with soft jaws; drill in a stand; drills 3 to 10.5 mm; countersink; M5 tap; hole saws 106 and 112 mm, or a router with a circle jig; jigsaw with metal and plastic blades; files and deburring tool; scriber, engineer's square, steel rule and calipers; hand sheet folder (or hardwood angle in the vice) for 2 and 3 mm aluminium up to 120 mm wide; tube cutter for 6 mm tubing; spanners for compression fittings; torque screwdriver; caulking gun; multimeter; conductivity meter; stopwatch; scale to 30 kg; nitrogen cylinder with a regulator to 0 to 400 kPa gauge for leak testing; leak detection fluid.

**Skills.** No certified trade is needed for the build. Basic metalwork (marking out, sawing, drilling, tapping, folding thin sheet), plastic sheet work, making compression fittings on small tubing, and low-voltage wiring. The mains side is a bought, earthed supply plugged into an RCD; no mains wiring is part of this build. Running the bench with hydrogen needs a supervisor trained in hydrogen handling.

**Workspace.** A bench about 1.5 x 0.8 m in a ventilated room; a metalwork corner kept apart from the electronics; for the first fill, a lab with an extraction route outdoors for the H2Guard duct.

**Personal protective equipment.** Safety glasses for cutting, drilling and all gas work; cut-resistant gloves for aluminium and polycarbonate; hearing protection when sawing; no gloves near a turning drill.

## 8. Where the numbers come from

- Model and constructability checks: `cad/src/model.py` (`python cad/src/model.py --check`, 135 checks); STEP and STL exports in `cad/step/` and `cad/stl/`.
- Pictures: `cad/src/build_plan_media.py`, using `.kit/build_views.py`; written to `docs/05-build-plan/` and `cad/drawings/HBN-DWG-101` to `HBN-DWG-114`.
- General arrangement: `cad/drawings/HBN-DWG-001.pdf`, Rev P3.
- Calculations: `docs/04-calcs/01-sizing.md` (HBN-CAL-001 v0.4) and `docs/04-calcs/sizing.py`; mass in section 9, cost in section 10.
- Bill of materials: `bom/bom.csv`.
- Decisions: `docs/decisions/0003-design-for-construction.md` (HBN-DDR-003), with HBN-DDR-001 and HBN-DDR-002; the register `docs/06-design-decisions.md` (HBN-DEC-001).
- Requirements: `docs/03-requirements.md` (HBN-REQ-001 v0.6).

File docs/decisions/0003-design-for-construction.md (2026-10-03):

---
doc_id: HBN-DDR-003
title: H2Bench design for construction
project: H2Bench
doc_type: Design decision record
version: "0.3"
status: Draft
date: '2026-10-02'
author: Amish Chadha
license: CERN-OHL-S-2.0
revisions:
- version: "0.1"
  date: '2026-10-01'
  author: Amish Chadha
  change: Changes that make the concept physically buildable, with the reason for each; made under Amish's 2026-09-30 instruction to make the design physically buildable; open for his review
- version: "0.2"
  date: '2026-10-02'
  author: Amish Chadha
  change: "Accepted by Amish (2026-10-02), with the recommendations for A1 and A2; status kept Draft"
- version: "0.3"
  date: '2026-10-02'
  author: Amish Chadha
  change: "Decisions A1 and the deoxidizer carried into the model: 144 checks, 24.4 kg, USD 1056"
---

# 0003: Design for construction

- **Date:** 2026-10-01
- **Status:** accepted. Amish, 2026-10-02: "i approve your recommendations for all 555 open decisions." This covers every change in Tables 1 and 2 and the recommendations for A1 and A2 in Table 3, which are now decided as recommended and recorded in the design decisions register (`docs/06-design-decisions.md`).

## Context

On 2026-09-30 Amish asked for every repo to have an illustrated build plan and wrote: "If you are realising that the design cannot be built as per concept - fix the design assumptions to match and be physically feasible as you draw the illustrations." The H2Bench model of HBN-DDR-002 showed what the bench does (the gas train, the tank, the hood and the meters) but was a massing model: several parts were fused shapes that cannot be cut or joined as drawn, several had no fixing, and the water side of the electrolyzer was not modelled at all.

Checking the concept model with build123d found: the tie rods of the electrolyzer cut 2 mm into its cell plates; the gas lines were seven separate pieces that did not join up; the front posts stood on the 6 mm drip lip; the canopy, the back panel and every component on the deck touched their neighbours but had nothing holding them. The rest of Table 1 comes from asking, for each part, how it is made and how it fastens to the next.

The changes keep what H2Bench does: the same 900 x 450 mm footprint (753 mm tall since the 10 mm deck of 2026-10-02), the same electrolyzer, 2 L tank, pressures, fuel cell, meters, hood and H2Guard positions, and the same gas path from stack to fuel cell. No energy, gas, pressure or venting figure in HBN-CAL-001 changes. Every change is in `cad/src/model.py`, which now builds each part separately and runs 144 constructability checks (`python cad/src/model.py --check`; 135 before the deoxidizer and 10 mm deck of 2026-10-02): no part overlaps another except where intended (a line pushed into its fitting, a rod through its nuts, the manifold in the tank neck), the pairs that must bear on or fasten to each other touch, the clearances hold, and every part is supported. All 144 pass.

## Decision

*Table 1. Changes made to the model, the BOM and the calculations.*

| # | Problem in the concept | Change made | Why this way |
| --- | --- | --- | --- |
| P1 | The frame was one fused shape: six bars overlapping at every corner, with no joints. | Six cut lengths of 20 x 20 mm slotted aluminium extrusion: two rails of 900 mm, two end rails and two cross rails of 410 mm between them, joined by eight inside corner brackets with M5 screws into drop-in T-nuts. | Standard 20-series parts, cut with a hacksaw; no welding (R14). |
| P2 | The drip lip was moulded into the HDPE deck. HDPE cannot be glued, and a lip cannot be cut from a 12 mm sheet. | A 10 x 10 x 1.5 mm aluminium angle screwed along the front and end edges on a bead of silicone, standing 10 mm above the deck (was 8 mm). The instrument panel closes the back edge. | Bought section, screwed, sealed. |
| P3 | Two front posts stood on the 6 mm lip with no fixing; the 3 mm polycarbonate canopy was cantilevered 345 mm behind them with nothing at the back; the back panel stood on the lip and touched nothing else. | Four posts of the same extrusion, each standing on the frame through a notch in the deck and held by inside corner brackets (two on a front post, one on a rear post). A top frame of the same extrusion joins the post tops (two rails of 860 mm, two of 305 mm, eight brackets). The canopy lies on the top frame on 12 screws. The panel screws to the front faces of the rear posts and stands on the deck on a silicone bead; it is 550 mm tall (was 570) so its top meets the side rails. | A closed frame carries the canopy and the H2Guard fan without sagging, and every joint is a standard bracket. |
| P4 | The 100 mm duct collar was fused into the canopy sheet. | A bought flanged 100 mm spigot through a 106 mm hole, flange on top on a silicone bead, four M4 screws. | Bought part; the H2Guard fan sits on the spigot as before. |
| P5 | The relief line ended flush against the underside of the canopy, which would block it; it was 300 mm long with no support; the vent valve had no line at all. | Both the relief line and a new vent line rise to an outlet hanger (20 x 20 x 2 mm angle) screwed under the canopy, are clipped to it, and end 7 mm below the sheet. | Gas leaves freely into the hood, where it rises to the H2Guard sensor and the duct, as the safety case assumes. |
| P6 | The water side of the electrolyzer was missing: no line from the reservoir or cartridge to the stack, and the oxygen port floated 10 mm off the cell block. A gravity-fed stack needs its reservoir above it. | Water ports moved to the back face of the left end plate (water in low, oxygen and water out high). The reservoir stands on a folded 60 mm aluminium stand; the deionizer cartridge (now 150 mm tall) stands beside it; three 6 mm water lines run reservoir to cartridge, cartridge to stack, and stack back to the reservoir top. Oxygen leaves through the reservoir's vented lid into the hood. | A sealed, primed line from a reservoir above the stack feeds it by gravity, with no pump, as small PEM stacks are run. |
| P7 | The electrolyzer's tie rods cut 2 mm into its cell plates, and its feet were two bars under the stack that could not be screwed down once the stack was on them. | Tie rods placed 6 mm outside the plates. Two feet of 40 x 20 x 3 mm aluminium angle, each bolted to an end plate by two M6 screws and to the deck by two 5 mm screws reachable beside the stack; the stack's base is 20 mm above the deck (was 13). | Every screw can be reached; the stack's own end plates carry it. |
| P8 | The separator and drier stood loose; the tube between them was 3 mm long, with no room for a fitting; the separator's water return to the reservoir came from a column at tank pressure with no valve. | A folded 3 mm aluminium column bracket behind both columns with a pipe clip round each. Gas leaves the top of the separator and loops over into the top of the drier; the drier's bottom outlet screws straight into the check valve and arrestor. The separator gets a manual drain valve at its foot. | Room for every fitting; nothing at tank pressure drains without a valve. (Draining by hand is Table 3, A2.) |
| P9 | The check valve and arrestor sat 150 mm up on a 15 mm post block, which put its outlet line into the tank. | The arrestor lies 60 mm above the table in an HDPE saddle with a band clip, straight off the drier outlet; the line to the tank rises at 108 mm, 9 mm clear of the tank and between the guard rods. | Short, supported run; every line clears the tank by 5 mm or more. |
| P10 | The tank stood on top of a solid block; the four guard rods stood on the deck with nothing holding them; the top of the guard was a 10 mm square ring that would have to be welded. | A 20 mm HDPE cradle with a 112 mm pocket 10 mm deep (the tank stands 8 mm lower than before). Four M10 stainless threaded rods screw into tee nuts pressed into the deck and are locked by nuts above it; a 4 mm aluminium top plate with a 130 mm opening is clamped between two nuts on each rod, 60 mm above the tank top. | No welding (R14); the tank cannot tip out of the pocket or lift past the plate. |
| P11 | The fuel cell stood on a solid block that would block the air its fan moves. | A folded 2 mm aluminium bridge, 40 mm tall, open at front and back. | Same height; the fan's air path stays clear. |
| P12 | The reservoir and cartridge stood loose. | A 200 mm length of the frame extrusion (the water post) stands between them, screwed to the deck from below before the deck goes on; a band clip holds each vessel to it. | Light vessels held at mid height by one standard part. |
| P13 | Nothing fixed the components to the deck. | Every mount (stand, feet, brackets, cradle, saddle, regulator, bridge, load case) is marked through its own holes onto the deck and fixed with 5 mm stainless self-tapping screws into 4 mm pilot holes. | HDPE holds self-tapping screws well; no access from below is needed after the deck is on. |

*Table 2. Knock-on changes.*

| Item | Change | Reason |
| --- | --- | --- |
| Mass | 28.0 kg with the bench supply (was 25.3 kg), 25.0 kg without it (was 22.3 kg) [HBN-CAL-001 section 9]. R13 stays at risk, now by 3.0 kg. Made parts are now weighed from their model volumes. | The rear posts, top frame and brackets add about 2.4 kg. |
| Cost | BOM lines 1, 3, 5, 6, 7, 8, 9, 12, 16 and 17 repriced for the parts added: USD 999 with the bench supply (was USD 885), USD 934 without it. Value-engineering target: USD 885. Estimated cost of the constructable design: USD 999 (USD 114 over the target). `budget_usd` unchanged. | Parts added for construction. |
| Guard clearance | Corrected from 18 mm to 50 mm. The concept note measured from the tank to a rod as if the rods stood on the axes; they stand at the corners of a 156 mm square. R15 stays met. | Calculation correction; no geometry change. |
| Drawing | HBN-DWG-001 Rev P3; making sketches HBN-DWG-101 to 114 added. | Follows the model. |
| Documents | HBN-CAL-001 v0.4, HBN-REQ-001 v0.6, HBN-PRC-001 v0.6: mass, cost, guard clearance and the constructable parts. No requirement changed status; cost (R14) is now reported against the value-engineering target rather than as met. | Follows the model. |
| Energy, gas and pressure | Unchanged: the tank volume, pressures, stack and fuel cell are the same, so every figure of HBN-CAL-001 sections 2 to 8 and 11 stands. | |

*Table 3. Items proposed to Amish; accepted as recommended on 2026-10-02.*

| # | Question | Options | Recommendation |
| --- | --- | --- | --- |
| A1 | Mass (R13, 25 kg or less) is now 28.0 kg with the bench supply. This replaces open item O4 of HBN-DDR-002. | (a) carry the bench supply separately (25.0 kg, exactly on the limit); (b) also use a 10 mm deck (24.2 kg); (c) raise R13 to 30 kg, since the bench is assembled on its table and moved in two parts; (d) look for lighter hood parts (a lighter canopy frame of 15 x 15 mm extrusion saves about 0.6 kg). | (a) and (b) together, which meets 25 kg with 0.8 kg to spare and changes nothing a student sees. Accepted 2026-10-02: the supply still ships in the kit but sits beside the bench; the 24.2 kg holds as long as the tank is aluminium. |
| A2 | The separator's water now returns to the reservoir by hand: the teacher opens the drain valve at the 20 kPa gauge holding pressure, catches the water and pours it back. The concept had a plumbed return. | (a) by hand, as modelled; (b) a plumbed return with a needle valve and a float trap. | (a) for the prototype: a few grams of water per fill, and nothing at tank pressure can drain on its own. Accepted 2026-10-02: drained by the teacher at 20 kPa gauge, under the hood, with H2Guard running. |

## Consequences

- `design_state: constructable` in `project.yaml`. The build plan HBN-BLD-001 shows every component and step in pictures generated from the model (`cad/src/build_plan_media.py`).
- With A1 accepted on 2026-10-02, the 10 mm deck and the supply beside the bench are carried into the model: 24.4 kg for the bench as moved (27.4 kg with the supply), so R13 is met. With A2 accepted, draining the separator by hand at 20 kPa gauge, under the hood with H2Guard running, is an operating rule.
- Requirement status after the 2026-10-02 decisions were carried into the model: 11 met, 3 at risk (R8, R9, R10), 1 not verifiable at TRL 3 (R16); cost (R14) is reported against the value-engineering target, USD 171 over it (USD 114 over at the 2026-10-01 construction changes, plus the USD 60 deoxidizer, less USD 3 for the deck).
- The photoreal renders (`media/render-*.png`), `media/card.png`, `media/social-preview.png` and the appearance model `cad/src/product_model.py` still show the concept: no rear posts, no top frame, the tank higher and the old mounts. They need updating on Amish's Mac, where Blender is.
- The stack's end-plate mounting holes, the tank neck thread, the fuel cell's mounting holes, the meters' bezel sizes and the reservoir's outlet are confirmed when the parts are bought (register, "To confirm when parts are bought").

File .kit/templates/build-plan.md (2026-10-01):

---
doc_id: PRJ-BLD-001
title: Project prototype build plan
project: Project name
doc_type: Build plan
version: "0.1"
status: Draft
date: YYYY-MM-DD
author: Amish Chadha
license: CERN-OHL-S-2.0
revisions:
  - version: "0.1"
    date: YYYY-MM-DD
    author: Amish Chadha
    change: First build plan; design made constructable
---

# Project prototype build plan

**Plan, not yet built.** How to build the first proof-of-concept prototype, component by component. Building and testing to it is TRL 4 work. Decisions still to be made are kept in the design decisions register (`docs/06-design-decisions.md`), not here.

## 1. What you are building

Every component, pulled apart and numbered in build order

One short paragraph: what the prototype is, how many components, which are made and which are bought, and the main ways they are made.

## 2. What changed to make it buildable

| Component | The concept had | The buildable design has | Why |
| --- | --- | --- | --- |

## 3. Making the components

### 3.1 Component name

Making sketch

**What it is and what it is made from.**

**How to make it.**

1. Mark out ...
2. Cut ...

**How it fits the parts next to it.**

Close-up of the joint

**Check before moving on.**

## 4. Putting it together

### Step 1: ...

Step 1

## 5. First checks

| Check | Requirement | How | Pass when |
| --- | --- | --- | --- |

## 6. Safety stops

## 7. Tools, skills and workspace

## 8. Where the numbers come from

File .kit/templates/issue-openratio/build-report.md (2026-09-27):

---
name: Build report
about: Tell us what happened when you built, printed or tested part of this design
title: "Build report: "
labels: build-report
---

This is a research and educational prototype, not a medical device. It is a TRL 3 concept and is not released for fabrication. If you build any part of it, you do so at your own risk. Reports help everyone.

**What you built** (part, sub-assembly or test)

**Materials, tools and settings**

**What worked**

**What did not work, with photos or measurements if you have them**

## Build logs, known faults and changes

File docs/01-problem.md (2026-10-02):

---
doc_id: HBN-PRB-001
title: H2Bench problem statement
project: H2Bench
doc_type: Problem statement
version: "0.7"
status: Draft
date: '2026-10-02'
author: Amish Chadha
license: CERN-OHL-S-2.0
revisions:
- version: "0.1"
  date: '2026-09-25'
  author: Amish Chadha
  change: Initial scaffold
- version: "0.2"
  date: '2026-09-25'
  author: Amish Chadha
  change: Populate to TRL 2 (users, context, constraints, out of scope, prior work with sources)
- version: "0.3"
  date: '2026-09-25'
  author: Amish Chadha
  change: TRL 3 update; record the first-user and storage choices adopted for TRL 3 (HBN-DDR-001), cost and inventory figures from HBN-CAL-001, MSE listing checked
- version: "0.4"
  date: '2026-09-25'
  author: Amish Chadha
  change: Recommendations accepted by Amish (DDR-002)
- version: "0.5"
  date: '2026-09-26'
  author: Amish Chadha
  change: Budget approved by Amish ($885)
- version: "0.6"
  date: '2026-10-01'
  author: Amish Chadha
  change: Budget restated as a value-engineering target; cost of the constructable design (HBN-DDR-003)
- version: "0.7"
  date: '2026-10-02'
  author: Amish Chadha
  change: "Curriculum and first use decided (HBN-DEC-001, 2026-10-02)"
---

# H2Bench problem statement

Students hear about the hydrogen economy but rarely measure it. Teaching kits are either toys that run a fan for a few minutes or lab systems priced for universities, and neither lets a class follow one quantity of energy from the wall socket, through hydrogen, and back to electricity while measuring every loss on the way.

## The problem

Governments and industry are committing large sums to hydrogen. The European Union aims to produce 10 Mt of renewable hydrogen a year by 2030 and import another 10 Mt ([European Commission](https://energy.ec.europa.eu/topics/eus-energy-system/hydrogen_en)); India targets 5 Mt a year under its National Green Hydrogen Mission ([PIB, Government of India](https://www.pib.gov.in/PressNoteDetails.aspx?id=155990&NoteId=155990&ModuleId=3)). Yet global demand was almost 100 Mt in 2024 and low-emissions hydrogen was still less than 1 % of production ([IEA, Global Hydrogen Review 2025](https://www.iea.org/reports/global-hydrogen-review-2025/executive-summary)). Engineers, technicians and policy makers will be asked to judge where hydrogen makes sense, and the core fact they need is quantitative: turning electricity into hydrogen and back loses most of the energy. A 2025 review puts the round trip with fuel cells at 27.4 to 48 % ([Oxford Institute for Energy Studies, 2025](https://www.oxfordenergy.org/wpcms/wp-content/uploads/2025/07/ET48-Power-to-Hydrogen-to-Power.pdf)).

Schools and colleges struggle to teach this by measurement:

1. **Toy kits hide the numbers.** Sub-watt reversible cells (from about $60 to $70, [Horizon Educational](https://www.horizoneducational.com/8-types-of-fuel-cell-by-price-point/t1418?currency=usd)) show that the reaction works, but at milliwatt scale the losses in meters, leaks and wiring swamp the result, and nothing is measured by default.
2. **Real components are costly.** A branded 12 W fuel cell stack lists at $482 to $576 ([Fuel Cell Store](https://www.fuelcellstore.com/horizon-12-watt-pem-fuel-cell), [Fuel Cell Shop](https://www.fuelcellshop.com/7-types-of-small-fuel-cell-by-price-point/t1363?currency=usd)) and a 300 mL/min PEM electrolyzer stack near $1,400 ([MSE Supplies](https://www.msesupplies.com/products/mse-pro-ma-300-pem-water-electrolyzer-stack-max-flow-rate-300-ml-min)), before any storage, safety or instrumentation.
3. **Safety is the gatekeeper.** Hydrogen burns in air from about 4 to 74 % by volume and ignites with about 0.02 mJ ([US DOE](https://www1.eere.energy.gov/hydrogenandfuelcells/pdfs/h2_safety_fsheet.pdf)). Many schools will not host a hydrogen rig without detection, ventilation and a limit on how much gas is present.

H2Bench is an open teaching bench at a scale large enough to measure (tens of watts) and small enough to be safe in a classroom (under 10 L of hydrogen, low pressure, interlocked by the portfolio's H2Guard detector).

## Users and context

| User | Need | Context |
| --- | --- | --- |
| Vocational hydrogen technician trainees (first users; decided by Amish, 2026-09-25, HBN-DDR-002) | Safe-handling practice on real hardware and measured efficiencies | Supervised courses with trained instructors |
| Secondary and vocational students (about 15 to 19 years) | See and measure each energy conversion; calculate efficiencies from their own data | 60 to 90 min practical sessions, groups of 3 to 5, supervised |
| University engineering students | Polarization curves, Faraday efficiency, gas law measurements, uncertainty analysis | Teaching lab, longer sessions, spreadsheet or notebook analysis |
| Technical and vocational trainers | A rig that trains safe habits: purge, leak check, interlock test, lockout | Hydrogen technician courses in countries building hydrogen industries |
| Teachers and lab technicians | Set up in under 15 min, run without specialist support, store safely between lessons | Existing lab benches, shared rooms, limited budgets |
| School safety officers | Evidence that the gas inventory, pressure and ventilation are bounded | Risk assessment before first use |

### Operating environment

- **Room:** a school or college lab of about 30 to 150 m³ with mechanical or window ventilation, mains power and an existing bench about 750 mm high.
- **Ambient:** 15 to 30 °C, indoor humidity; the fuel cell class chosen is specified for 5 to 30 °C ambient ([Fuel Cell Store](https://www.fuelcellstore.com/horizon-12-watt-pem-fuel-cell)).
- **Water:** deionized or distilled water is needed; PEM stacks are damaged by other water ([MSE Supplies](https://www.msesupplies.com/products/mse-pro-ma-300-pem-water-electrolyzer-stack-max-flow-rate-300-ml-min)).
- **Use pattern:** one fill and one discharge per lesson, a few lessons a week, tank vented down to about 20 kPa gauge (never to atmospheric, so no air enters) at the end of each day, through a needle valve over 3 min or more (HBN-CAL-001).

## Constraints

- Garage-buildable prototype: hand tools only, no welding. Value-engineering target: USD 885 (`budget_usd`; raised from $450 to $850 on 2026-09-25 and to $885 on 2026-09-26, HBN-DDR-002; a hypothetical control target, not a limit), with the bench power supply in the kit and H2Guard costed in its own project. Estimated cost of the constructable design: USD 999 (USD 114 over the target), or USD 934 without the bench supply (HBN-CAL-001 v0.4).
- Hydrogen inventory under 10 L at 20 °C and 101.3 kPa, stored at 300 kPa gauge or less in a rigid tank, with a 310 kPa gauge supply cut and a 325 kPa gauge relief (decided, HBN-DDR-002). No compression beyond what the electrolyzer does itself.
- Electrolyzer under 100 W and fuel cell under 50 W, as the pitch states.
- Operates only when the H2Guard detector, extraction fan and interlock are active.
- Off-the-shelf gas components; no welding or pressure-vessel fabrication.
- Fits on a standard lab bench; carried by two people.
- Open design files (CERN-OHL-S-2.0) and open worksheets so teachers can adapt the lessons.

## Out of scope

- Hydrogen for heating, cooking or vehicles, and any storage above 1 MPa.
- Alkaline electrolysis with caustic electrolyte (excluded for student safety).
- Metal hydride storage in the first version (kept as an option, see HBN-PRC-001).
- Designing the hydrogen detector and interlock itself (that is H2Guard).
- Certification as laboratory equipment; this is a research and teaching prototype.

## Prior work

- **Educational fuel cell kits.** Horizon Educational and similar suppliers sell kits from sub-watt reversible cells to 12 to 30 W stacks ([Horizon Educational](https://www.horizoneducational.com/8-types-of-fuel-cell-by-price-point/t1418?currency=usd)). They prove the components work in schools; the larger stacks set the cost floor.
- **Laboratory PEM electrolyzers.** Small stacks such as MSE's 300 mL/min single-cell unit (56 cm², 45 A at about 2.3 V, 2.5 kg, $1,396.95) show the output class needed ([MSE Supplies](https://www.msesupplies.com/products/mse-pro-ma-300-pem-water-electrolyzer-stack-max-flow-rate-300-ml-min), checked 2026-09-25). That listing does not state an output pressure, so whether a stack can fill a low-pressure tank directly must be confirmed per stack (HBN-REQ-001 R10).
- **Hydrogen education programs.** The US DOE Hydrogen Program names teachers and students among its target audiences and notes "a general lack of awareness of hydrogen as an energy alternative" ([US DOE Hydrogen Program](https://www.hydrogen.energy.gov/program-areas/education)). EPRI's H2EDGE program develops hydrogen training for the workforce ([EPRI](https://hydrogen.epri.com/en/h2edge.html)).
- **Round-trip analysis.** Published studies of power-to-hydrogen-to-power give the efficiency range that students should be able to reproduce at small scale ([Oxford Institute for Energy Studies, 2025](https://www.oxfordenergy.org/wpcms/wp-content/uploads/2025/07/ET48-Power-to-Hydrogen-to-Power.pdf)).
- **H2Guard (this portfolio).** The hydrogen leak detector and ventilation interlock that H2Bench depends on. H2Bench adds no detection of its own.

## Open questions

- Which curricula to align with first? Decided by Amish, 2026-10-02 (HBN-DEC-001): post-16 vocational learners on hydrogen or renewable energy technician courses, aligned to the electrochemistry, gas safety and efficiency units of the first partner college's course.
- Will school safety officers accept a 300 kPa gauge buffer tank, or is a near-atmospheric gasbag with a small pump easier to approve?
- Is a class demonstration (teacher-run) or a group practical (student-run) the first use case? Decided by Amish, 2026-10-02 (HBN-DEC-001): an instructor-run class demonstration first; group practicals only after a recorded run of attended fills with H2Guard tested before each.

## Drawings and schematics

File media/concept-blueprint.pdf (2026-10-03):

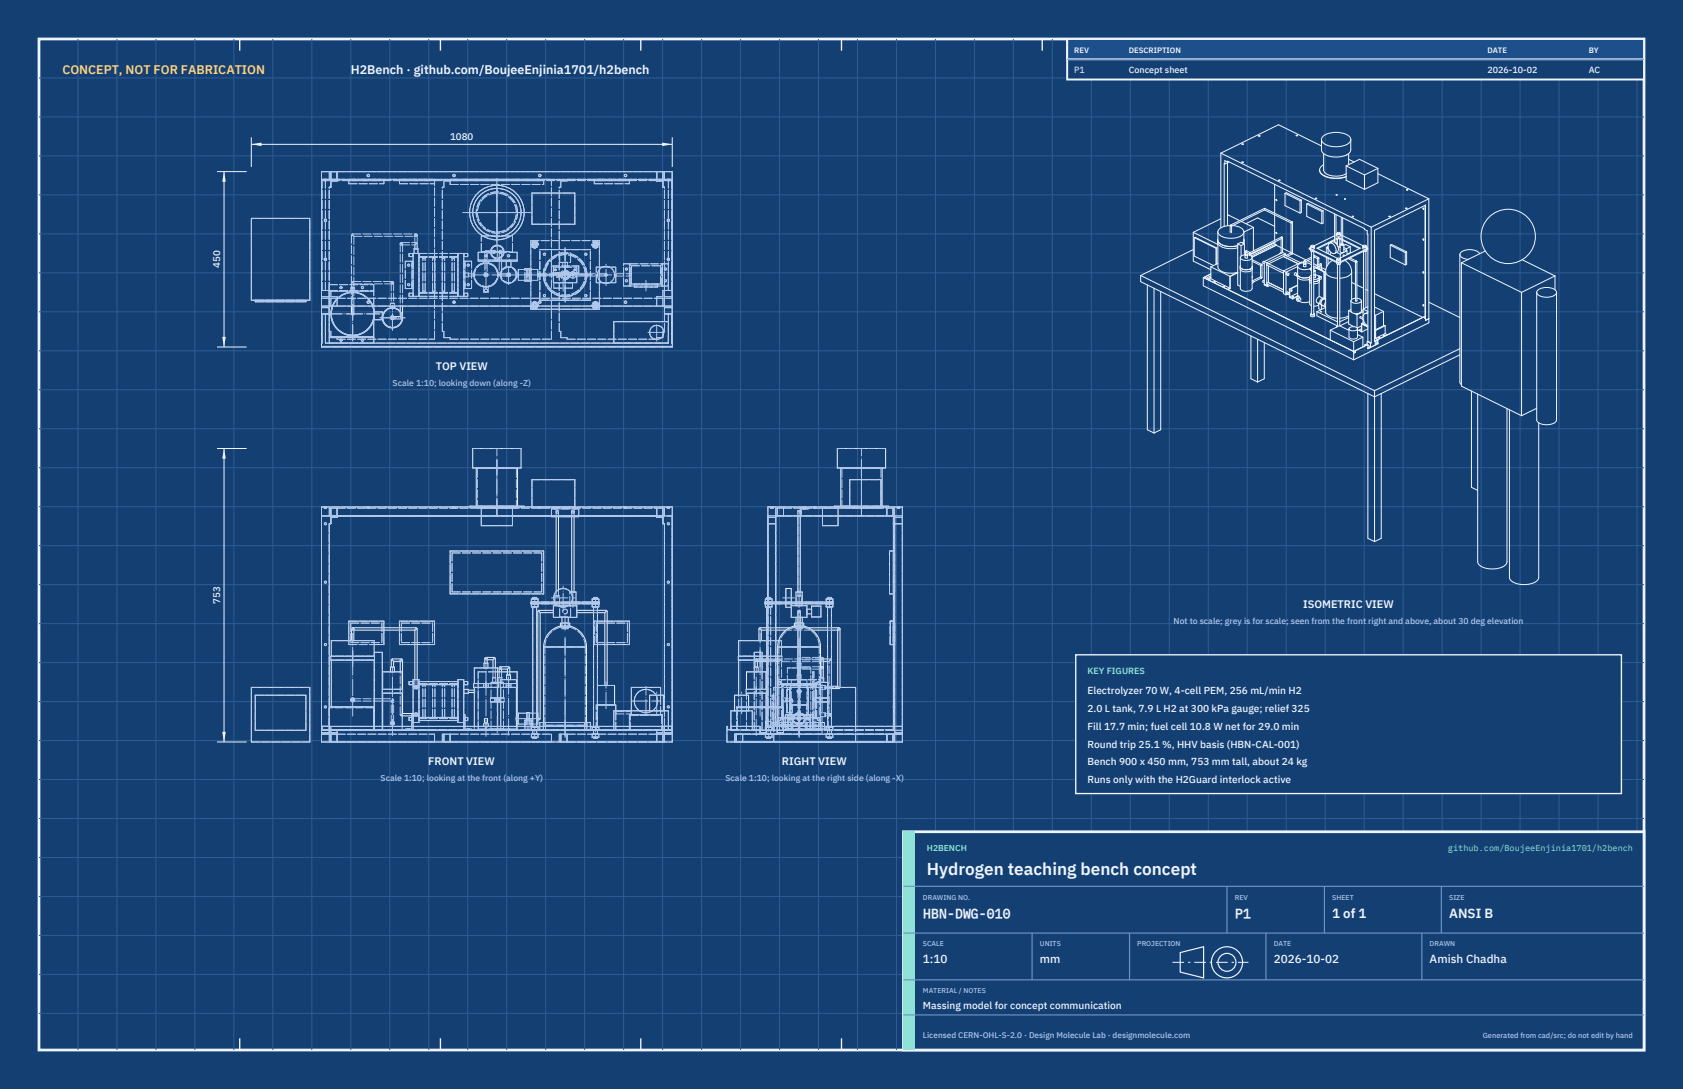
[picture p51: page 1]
CONCEPT, NOT FOR FABRICATION; H2Bench · github.com/BoujeeEnjinia1701/h2bench; FRONT VIEW; TOP VIEW; RIGHT VIEW; ISOMETRIC VIEW; REV; DESCRIPTION; DATE; Concept sheet; H2BENCH; github.com/BoujeeEnjinia1701/h2bench; DRAWING NO. HBN-DWG-010; REV P1; SHEET 1 of 1; SIZE ANSI B; SCALE 1:10; UNITS mm; PROJECTION; DRAWN Amish Chadha; Licensed CERN-OHL-S-2.0 · Design Molecule Lab · designmolecule.com; Generated from cad/src; do not edit by hand

Scale 1:10; looking down (along -Z)

Not to scale; grey is for scale; seen from the front right and above, about 30 deg elevation

KEY FIGURES
Electrolyzer 70 W, 4-cell PEM, 256 mL/min H2
2.0 L tank, 7.9 L H2 at 300 kPa gauge; relief 325
Fill 17.7 min; fuel cell 10.8 W net for 29.0 min
Round trip 25.1 %, HHV basis (HBN-CAL-001)
Bench 900 x 450 mm, 753 mm tall, about 24 kg
Runs only with the H2Guard interlock active

Scale 1:10; looking at the front (along +Y)

Scale 1:10; looking at the right side (along -X)

Hydrogen teaching bench concept

MATERIAL / NOTES
Massing model for concept communication

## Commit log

2026-09-25 Initial scaffold: standard open hardware layout, CERN-OHL-S v2 + MIT licenses
    Claude-Session: https://claude.ai/code/session_01XuhhSU4W6fYhgCfURbrkut
    [bom.csv]
2026-09-25 Populate to TRL 2: problem, requirements, precis, concept media, BOM and README use cases
    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
    [bom.csv]
2026-09-26 Advance to TRL 3: DDR-001, CAL-001 sizing, parametric model with STEP/STL, GA drawing, priced BOM; TRL 4 on hold
    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
    [bom.csv, h2bench-assembly.step, h2bench-assembly.stl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]
2026-09-26 Accept all recommendations (DDR-002), switch footer to designmolecule.com, add README write-up with new inspiration point
    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
    [bom.csv, h2bench-assembly.step, h2bench-assembly.stl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]
2026-09-26 Strengthen sources, apply approved budgets, add CITATION.cff and CONTRIBUTORS.md with credits
    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
    [results.csv]
2026-09-27 Product appearance model and photoreal renders
    Adds cad/src/product_model.py (appearance model for renders only, all main
    dimensions from model.py) and Blender renders in media/render-*.png,
    captioned with the project, repository and viewing direction. README leads
    with the product render; trl stays 3.
    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
2026-10-01 Image quality pass: legible exploded views, flow diagrams and drawing sheets
    Kit 1.6.1 image layout: the parts list sits in its own column, number bubbles sit on visible parts and never overlap, small parts get a leader, pictures are cropped to the subject, flow labels keep numbers with their units, and sheet captions and the revision table no longer overprint. Concept images, blueprint and general arrangement sheet regenerated; repo-specific labels moved clear of other text and lines.
2026-10-01 Kit 1.7.0: constructable design, illustrated build plan and design decisions register
    The design is now constructable: every part can be made and fits its neighbours, with each change recorded in a Design for construction decision record (made under Amish's 2026-09-30 instruction; ope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
    FlexHand also credits Dr. Geeti Chadha as a contribut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
    [bom.csv, h2bench-assembly.step, h2bench-assembly.stl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]
2026-10-02 Record Amish's approval of the open-decision recommendations
    Amish approved the recommendation on every open decision in the design decisions register ("i approve your recommendations for all 555 open decisions.", 2026-10-02). Each decision is moved to Decisio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
2026-10-03 Carry approved follow-ups into the design and redo photoreal renders
    Amish approved the follow-up actions from the open-decision sign-off ("APPROVED CHANGES, COMPLETE THESE", 2026-10-02), the design-for-construction change tables in ten repos, the last wave's open dec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
    [bom.csv, h2bench-assembly.step, h2bench-assembly.stl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]

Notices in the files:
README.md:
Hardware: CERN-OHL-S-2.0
